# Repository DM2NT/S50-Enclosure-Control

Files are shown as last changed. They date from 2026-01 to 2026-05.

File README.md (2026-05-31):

# Seestar S50 Observatory Controller

**ESP32-basierte Wetterstation und automatische Schutzabdeckung für das Seestar S50 Teleskop**

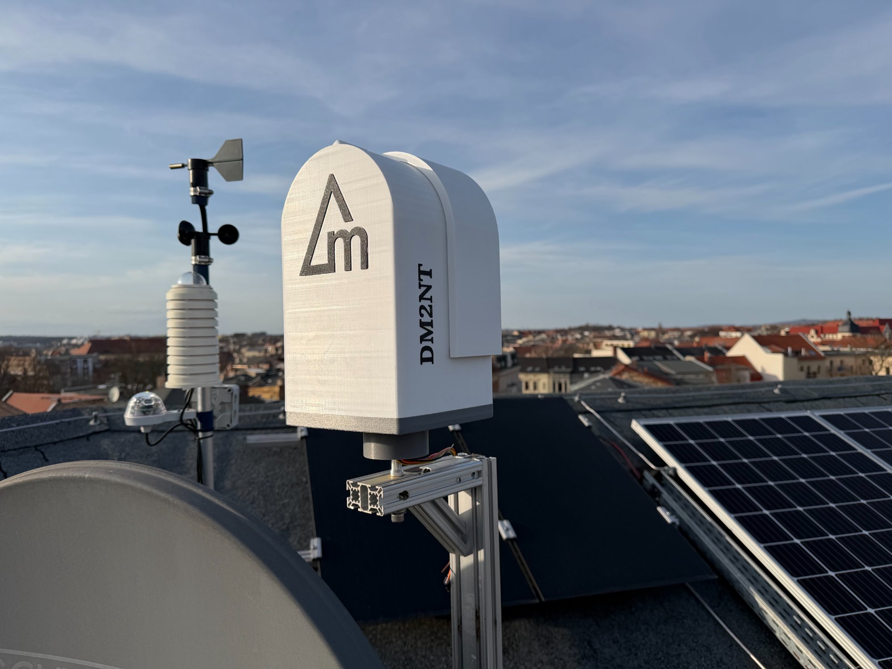
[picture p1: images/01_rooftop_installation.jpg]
Rooftop Installation


## Übersicht

Dieses Projekt bietet eine vollautomatische Wetterüberwachung und Teleskopschutz-Lösung für das Seestar S50. Bei ungünstigen Wetterbedingungen (Regen, Wind, hohe Luftfeuchtigkeit) schließt sich die motorisierte Abdeckung automatisch, um das Teleskop zu schützen.

**Hauptfunktionen:**
- ✅ Automatische Regenüberwachung (Hydreon RG-11)
- ✅ Temperatur- und Luftfeuchtigkeits-Überwachung (BME280)
- ✅ Taupunktberechnung mit Heizungssteuerung
- ✅ Motorisierte Schutzabdeckung (MG996R Servo)
- ✅ Seestar S50 Integration (automatisches Parken bei Schlechtwetter)
- ✅ Web-Interface für Steuerung und Monitoring
- ✅ GPS-Zeitabgleich (optional)

## Hardware

### Hauptkomponenten

| Komponente | Modell | Funktion |
|---|---|---|
| Mikrocontroller | ESP32 DevKit | Hauptsteuerung |
| Regensensor | Hydreon RG-11 | Niederschlagserkennung |
| Umweltsensor | BME280 | Temperatur, Luftfeuchtigkeit, Luftdruck |
| Servo | MS24 20kg | Abdeckungsmechanik |
| GPS-Modul | NEO-6M/7M | Zeitabgleich (optional) |
| Heizung | 3 Ohm 15W | Taupunkt-Schutz |

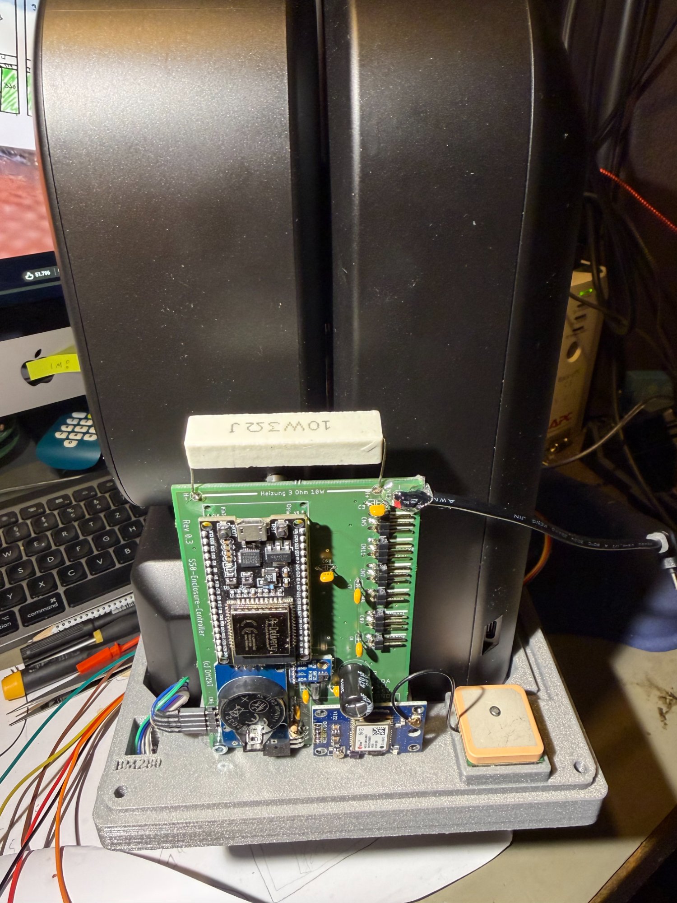
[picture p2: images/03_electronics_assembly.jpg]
Electronics Assembly


### Gehäuse

Das Gehäuse wurde mit einem **Bambu Lab 3D-Drucker** gefertigt:
- Material: PLA/PETG
- Wetterfest konzipiert
- Kabelführungen integriert
- Montage-Interfaces für Sensoren

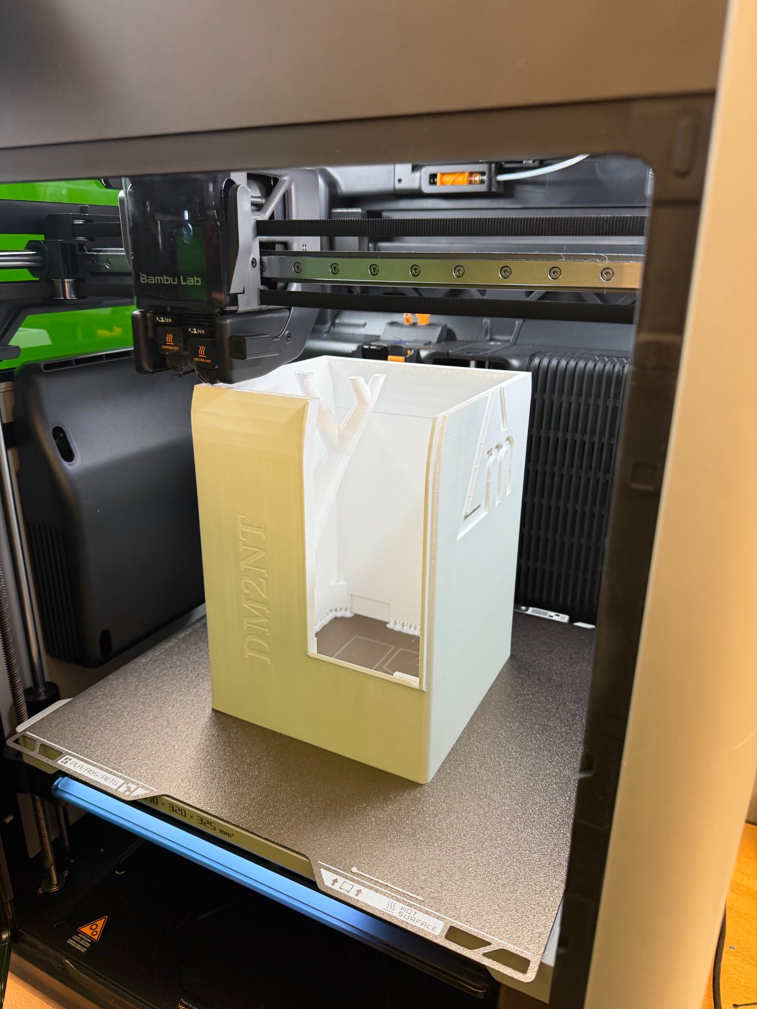
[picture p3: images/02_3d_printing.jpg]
3D Printing


## Pin-Belegung

### ESP32 Pins

```cpp
// Servo
#define SERVO_PIN 13

// Reed-Schalter (Position)
#define REED_CLOSED_PIN 32
#define REED_OPEN_PIN 33

// Wind-Sensor (Davis 6410)
#define WIND_PIN 27

// Heizung
#define HEATER_PIN 12

// RG-11 Regensensor
#define RAIN_RX_PIN 35
#define RAIN_TX_PIN 4

// GPS (optional)
#define GPS_RX_PIN 16
#define GPS_TX_PIN 17

// I2C (BME280)
SDA: GPIO 21
SCL: GPIO 22
```

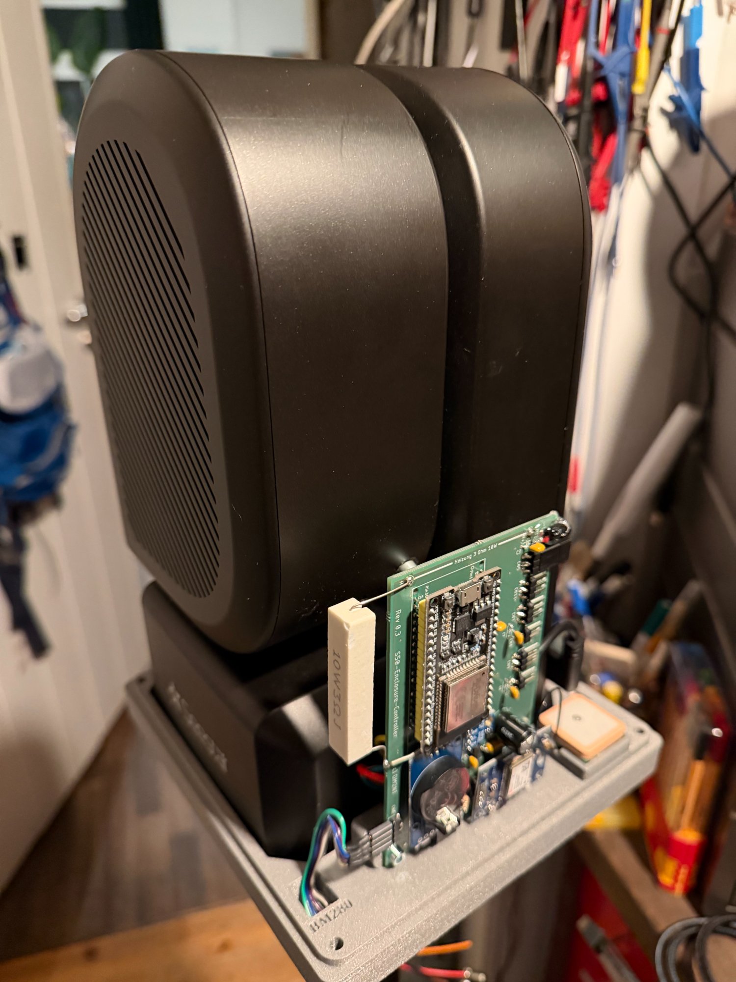
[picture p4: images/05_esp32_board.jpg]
ESP32 Board


## Installation

### 1. Arduino IDE Setup

```bash
# ESP32 Board Manager URL hinzufügen:
https://raw.githubusercontent.com/espressif/arduino-esp32/gh-pages/package_esp32_index.json

# Benötigte Bibliotheken installieren:
- ESP32Servo
- Adafruit BME280
- TinyGPSPlus
- AsyncTCP
- ESPAsyncWebServer
- Preferences
```

### 2. Firmware flashen

1. `.ino` Datei in Arduino IDE öffnen
2. Board auswählen: **ESP32 Dev Module**
3. Partition Scheme: **Minimal SPIFFS (1.9MB APP with OTA)**
4. Upload Speed: **921600**
5. Kompilieren und hochladen

### 3. Erste Konfiguration

Nach dem ersten Start öffnet der ESP32 einen **WiFi Access Point**:

```
SSID: S50-Enclosure-XXXXXX
Passwort: 12345678
IP: 192.168.4.1
```

Verbinden und WiFi-Zugangsdaten eingeben.

## Konfiguration

### RG-11 Regensensor DIP-Switches
!!! im Moment nicht funktionsfähig !!!

**Für ASCII "It's Raining" Mode:**

| DIP | Position | Funktion |
|-----|---|---|
| 1 | **ON** | Empfindlichkeit hoch |
| 2 | **ON** | Empfindlichkeit hoch |
| 3 | OFF | Keine 15-Min-Haltezeit |
| 5 | OFF | RS232 aktiv |
| 7 | **ON** | It's Raining Mode |
| 8 | OFF | Normal (kein Sleep) |

**Wichtig:** DIP 5 MUSS OFF sein für RS232!

### Heizungssteuerung

- Aktiviert wenn: `Temperatur < (Taupunkt + Hysterese)`
- Standard-Hysterese: **2.0°C**
- Heizleistung: **15W** (3 Ohm)

## Web-Interface

Das Web-Interface ist erreichbar unter der ESP32-IP:

**Hauptseite:**
- Live-Sensordaten (2s Refresh)
- Status: Regen, Wind, Temperatur, Luftfeuchtigkeit
- Steuerung: Öffnen, Schließen, Stopp
- Seestar S50 Status

**Einstellungen:**
- WiFi-Konfiguration
- Wind-Schwellwert  ( nicht integriert )
- Heizungs-Hysterese
- Seestar IP-Adresse
- GPS An/Aus

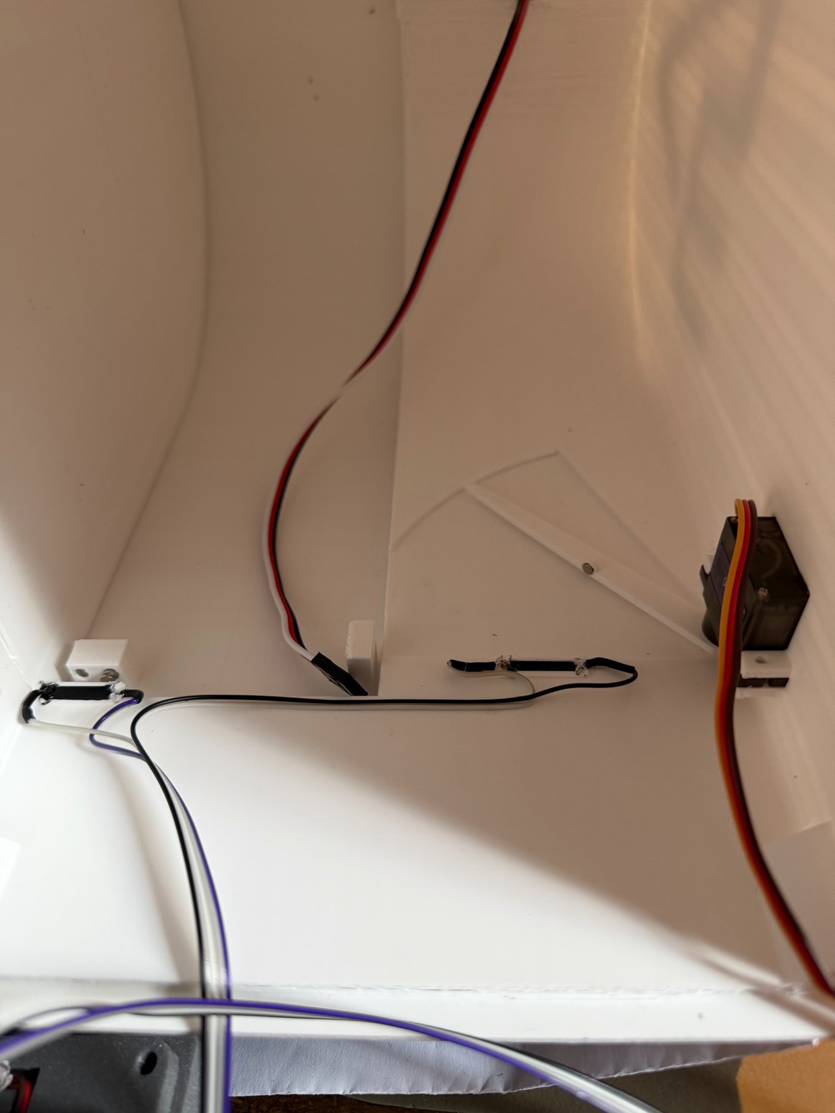
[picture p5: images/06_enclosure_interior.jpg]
Enclosure Interior


## Servo-Mechanik

Der Servo MS24 mit 20kg Drehmoment steuert die Abdeckung:

- Öffnen: 0° (Reed-Schalter 2)
- Geschlossen: 90° (Reed-Schalter 1)
- Sanftes Anfahren mit Beschleunigung
- Reed-Schalter als Endlagen-Sicherung

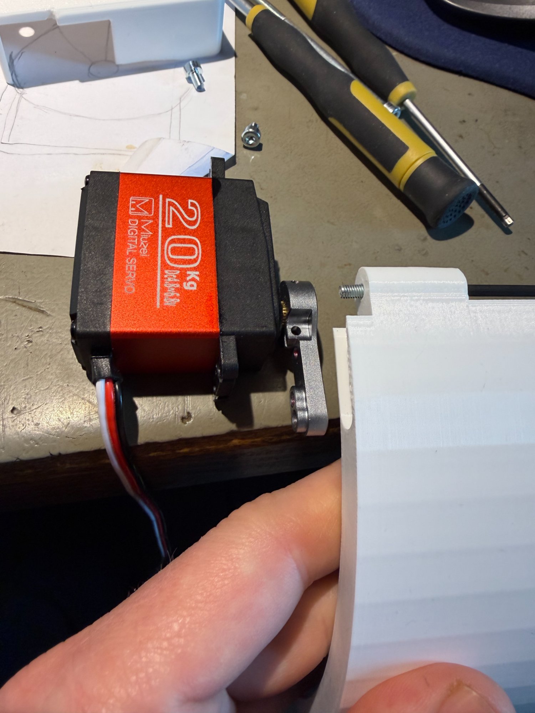
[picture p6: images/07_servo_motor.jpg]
Servo Motor

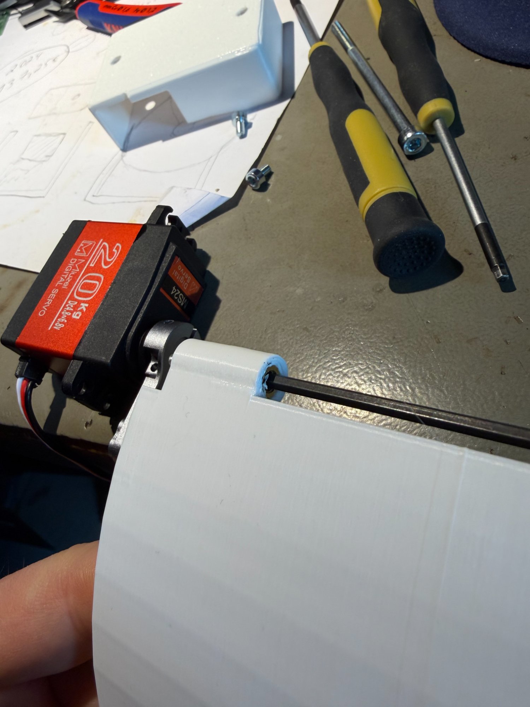
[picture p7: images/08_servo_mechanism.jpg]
Servo Mechanism


### 3D-gedruckte Teile

- Servo-Halterung
- Hebelarm (weiß, verstärkt)
- Gehäuse-Adapter

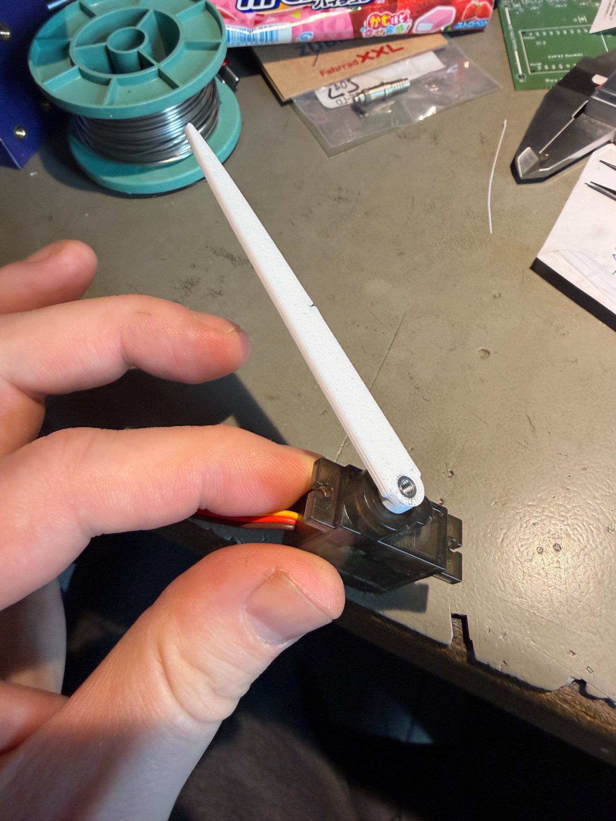
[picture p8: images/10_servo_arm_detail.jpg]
Servo Arm Detail


## Seestar S50 Integration

Bei Regen/Wind schaltet der Controller das Seestar automatisch ab und schließt die Klappe.

- im Moment nicht funktionsfähig

Das Teleskop wird geparkt, bevor die Abdeckung schließt.

## Sicherheitsfunktionen

1. **Regen-Notschließung:** Bei Regenerkennung → sofortige Schließung
2. **Wind-Notschließung:** Bei Überschreitung Schwellwert → Schließung
3. **Reed-Schalter:** Mechanische Endlagen-Sicherung
4. **Motor-Timeout:** Stoppt nach 10s bei fehlendem Reed-Signal
5. **Heizung:** Verhindert Beschlagen/Betauung

## OTA-Updates

Firmware-Updates über WiFi möglich:

```
http://ESP32_IP/update
```

**Wichtig:** Nur `.ino.bin` verwenden, NICHT `merged.bin`!

## Serial Monitor Debug

USB Serial (115200 Baud):
```
RG-11 UART initialisiert (RX=35, 9600 Baud, ASCII Mode)
  Warte auf RG-11 ASCII Daten (max 10s)...
  'Acc' Frame gefunden: Acc 0.00
✓ RG-11 Regensensor erkannt!

💧 RG-11: REGEN! Acc=1.00
⚠️ REGEN ERKANNT! (Acc=1.00) Starte Notschließung...
```

## Stromversorgung

- 5V 4A externes Netzteil 

**Wichtig:** Servo und ESP32 gemeinsame GND-Verbindung!

## Versionshistorie

- **v3.1** - ASCII-Protokoll RG-11, Boot-Erkennung angepasst
- **v3.0** - Umstellung auf ASCII "It's Raining" Mode
- **v2.2** - Slow Register #8 Bucket-Zähler
- **v0.4** - Heizung auf Innentemperatur, stabile Version

## Lizenz

MIT License - siehe LICENSE Datei

## Autor

**DM2NT** - Amateur Radio / Astrophotography  
YouTube: [DeltaMike2 Astronomie](https://youtube.com/@DeltaMike2)

## Danksagungen

Allen Irren, die sich das hier antun.

---

**73!** 📡🔭

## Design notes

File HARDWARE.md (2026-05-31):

# Hardware-Dokumentation

## Vollständige Komponentenliste

### Elektronik

| Komponente | Modell/Spezifikation | Menge | Beschaffung |
|---|---|---|---|
| ESP32 | DevKit V1 (30 Pin) | 1 | AliExpress/Amazon |
| Regensensor | Hydreon RG-11 | 1 | Hydreon/Conrad |
| Umweltsensor | BME280 (I2C) | 1 | Adafruit/AliExpress |
| Servo | MG996R 20kg | 1 | Amazon/AliExpress |
| GPS-Modul | NEO-6M oder NEO-7M | 1 | AliExpress (optional) |
| Reed-Schalter | NO (Normally Open) | 2 | Conrad/Reichelt |
| Heizwiderstand | 3 Ohm 15W | 1 | Reichelt |
| MOSFET | IRLZ44N | 1 | Reichelt |
| Widerstände | 10kΩ | 3 | Reichelt |
| Diode | 1N4007 | 1 | Reichelt |

### Mechanik & Gehäuse

| Komponente | Material | Hinweise |
|---|---|---|
| Gehäuse | PLA/PETG | 3D-Druck, wetterfest |
| Servo-Halterung | PETG | 3D-Druck, verstärkt |
| Hebelarm | PLA | 3D-Druck, weiß |
| M3 Schrauben | Edelstahl | Diverse Längen |
| M4 Schrauben | Edelstahl | Servo-Befestigung |

### Kabel

| Typ | Spezifikation | Länge | Verwendung |
|-----|---|---|---|
| Stromkabel | 1.5mm² | Variabel | 230V → Netzteile |
| Signalkabel | 0.5mm² geschirmt | 5m | RG-11, Anemometer |
| Dupont-Kabel | Female-Female | 20cm | ESP32-Verbindungen |
| USB-Kabel | Micro-USB | 2m | ESP32 Stromversorgung |

### Netzteile

| Ausgang | Leistung | Verwendung |
|---|---|---|
| 5V DC | 4A | Platine |

## Detaillierte Verkabelung

### ESP32 Pinout

```
                    ESP32 DevKit V1
                  ┌─────────────────┐
              3V3 │1              30│ GND
              GND │2              29│ GPIO 23
      (Touch) D15 │3              28│ GPIO 22 ──┐ SCL (BME280)
      (Touch)  D2 │4              27│ TXD      │
      (Touch)  D4 │5              26│ RXD      │
              D16 │6 GPS_RX       25│ GPIO 21 ─┼─ SDA (BME280)
              D17 │7 GPS_TX       24│ GND      │
               D5 │8              23│ GPIO 19  │
              D18 │9              22│ GPIO 18  │
              D19 │10             21│ GPIO 5   │
              GND │11             20│ GPIO 17  │
              D21 │12             19│ GPIO 16  │
       RX0    D3  │13             18│ GPIO 4  ─── RAIN_TX
       TX0    D1  │14             17│ GPIO 2   │
      (Touch) D22 │15             16│ GPIO 15  │
              D23 │16             15│ GND      │
              GND │17             14│ GPIO 13 ─── SERVO_PIN
              3V3 │18             13│ GPIO 12 ─── HEATER_PIN
               EN │19             12│ GPIO 14  │
     ADC2_0   VP  │20             11│ GPIO 27 ─── WIND_PIN
     ADC2_3   VN  │21             10│ GPIO 26  │
   ADC2_4/34  D34 │22              9│ GPIO 25  │
   ADC2_5/35  D35 │23 RAIN_RX      8│ GPIO 33 ─── REED_OPEN
   ADC2_6/32  D32 │24 REED_CLOSED  7│ GPIO 32  │
   ADC2_7/33  D33 │25              6│ TDI/D5   │
   ADC1_4/25  D25 │26              5│ 3V3      │
   ADC1_5/26  D26 │27              4│ TDO/D18  │
   ADC1_6/27  D27 │28              3│ D23      │
   ADC1_7/14  D14 │29              2│ D22      │
   ADC1_0/12  D12 │30              1│ TXD      │
                  └─────────────────┘
```

### RG-11 Regensensor

**Anschluss:**
```
RG-11          ESP32
────────────────────────────
1 (+12V)   →   Externes 12V Netzteil
2 (GND)    →   GND (gemeinsam)
3 (OUT)    →   Pin 35 (RAIN_RX)
               + 10kΩ Pull-Down zu GND
```

**Wichtig:**
- RG-11 sendet 5V → direkter Anschluss an ESP32 ist OK (INPUT_ONLY Pin 35)
- Pull-Down Widerstand verhindert "floating" Pin
- UART Konfiguration: 9600 Baud, 8N1, ASCII Mode

**DIP-Switch Einstellung:**
```
┌─────────────────────────────┐
│  1  2  3  4  5  6  7  8     │
│ ON ON OFF OFF OFF OFF ON OFF│
└─────────────────────────────┘
```

### Davis Anemometer 6410

**Anschluss:**
```
Davis 6410     ESP32
────────────────────────────
Schwarz    →   Pin 27 (WIND_PIN)
Rot        →   3.3V
Grün       →   GND
Gelb       →   Nicht verbunden
```

**Schaltung:**
```
3.3V ──┬── 10kΩ ──┬── Pin 27
       │          │
       └── Reed ──┘ (im Anemometer)
                  │
                 GND
```

**Funktionsweise:**
- Jede Umdrehung → 1 Impuls (Reed-Schalter)
- Wind-Geschwindigkeit = `(1492 / T) * 1.60934` km/h
- T = Zeit zwischen Impulsen in ms

### BME280 Umweltsensor

**Anschluss (I2C):**
```
BME280         ESP32
────────────────────────────
VCC        →   3.3V
GND        →   GND
SCL        →   Pin 22 (SCL)
SDA        →   Pin 21 (SDA)
```

**I2C-Adresse:** `0x76` (Standard) oder `0x77`

### Servo MG996R

**Anschluss:**
```
Servo          Versorgung
────────────────────────────
Braun (GND) →  GND (gemeinsam mit ESP32!)
Rot (VCC)   →  5V/2A Netzteil
Orange (PWM)→  Pin 13 (ESP32)
```

- GND zwischen ESP32 und Servo-Netzteil verbinden

**Position:**
- 0° = Offen
- 90° = Geschlossen
- Sanfte Bewegung (1° pro 20ms)

### Reed-Schalter (Endlagen)

**Geschlossen-Position:**
```
Reed 1         ESP32
────────────────────────────
Pin 1      →   Pin 32 (REED_CLOSED)
Pin 2      →   GND
```

**Offen-Position:**
```
Reed 2         ESP32
────────────────────────────
Pin 1      →   Pin 33 (REED_OPEN)
Pin 2      →   GND
```

**Funktionsweise:**
- `INPUT_PULLUP` Mode
- Geschlossen: LOW = Magnet in Nähe
- Offen: HIGH = kein Magnet

### Heizung (Taupunkt-Schutz)

**Schaltung:**
```
12V ──┬── Heizwiderstand 3Ω/15W ──┬── GND
      │                           │
      └── MOSFET (IRLZ44N) ───────┘
              │
              ├── Gate: Pin 12 (ESP32)
              ├── 10kΩ Pull-Down (Gate-GND)
              └── 1N4007 Diode (parallel zum Widerstand)
```

**PWM-Steuerung:**
- Frequenz: 1000 Hz
- Duty Cycle: 0-255 (aktuell: 255 = 100%)

### GPS-Modul (Optional)

**Anschluss:**
```
GPS NEO-6M     ESP32
────────────────────────────
VCC        →   3.3V (NICHT 5V!)
GND        →   GND
TX         →   Pin 16 (GPS_RX)
RX         →   Pin 17 (GPS_TX)
```

**UART:** 9600 Baud, 8N1

## Montage-Hinweise

### Gehäuse

1. **3D-Druck Einstellungen:**
   - Layer: 0.2mm
   - Infill: 20%
   - Wandstärke: 3-4 Perimeter
   - Support: Ja (für Überhänge)

2. **Wetterfest machen:**
   - Alle Kabel-Durchführungen mit Silikon abdichten
   - Reed-Schalter in wasserdichten Gehäusen
   - RG-11 nach oben montieren (Kabel nach unten)

3. **Kabelführung:**
   - Zugentlastung vorsehen
   - Kabelbinder verwenden
   - Beschriftung empfohlen

### Servo-Mechanik

1. **Hebelarm:**
   - 3D-gedruckt aus PLA/PETG
   - Verstärkung mit 100% Infill
   - M3 Schraube zur Befestigung

2. **Servo-Halterung:**
   - Mit M4 Schrauben am Gehäuse befestigen
   - Spielfrei montieren
   - Bewegungsfreiheit prüfen

### Sensor-Platzierung

**RG-11 Regensensor:**
- Horizontal montieren
- Freie Sicht nach oben (keine Überhänge)
- Mindestens 30cm von Wänden entfernt

**BME280:**
- Im Gehäuse, aber belüftet
- Vor direkter Sonneneinstrahlung schützen
- Nicht direkt über Heizung

## Stromverbrauch

| Komponente | Standby | Aktiv | Max |
|---|---|---|-----|
| ESP32 | 80mA | 150mA | 250mA |
| Servo | 10mA | 500mA | 2A |
| BME280 | 3µA | 3mA | 5mA |
| GPS | 20mA | 50mA | 50mA |
| Heizung | 0mA | 1.25A | 1.25A |
| **Gesamt** | ~100mA | ~700mA | ~3.5A |

## Fehlersuche Hardware

### RG-11 keine Daten

1. DIP-Switches prüfen (Foto im Web suchen)
2. 12V Versorgung messen
3. Pull-Down Widerstand 10kΩ vorhanden?
4. Serial Monitor: Zeichen empfangen?

### Servo ruckt/zittert

1. SStromversorgung 5V/2A prüfen
2. GND-Verbindung ESP32 ↔ Servo OK?
3. Kabel zu lang? (max 50cm empfohlen)
4. Mechanische Blockade?

### Heizung funktioniert nicht

1. MOSFET richtig gepolt?
2. Pull-Down 10kΩ Gate-GND vorhanden?
3. Freilauf-Diode 1N4007 vorhanden?
4. 5V Versorgung messen

### BME280 nicht erkannt

1. I2C-Adresse prüfen: `0x76` oder `0x77`
2. SDA/SCL vertauscht?
3. Pull-Up Widerstände vorhanden? (meist auf Modul)
4. 3.3V (NICHT 5V!)

### Reed-Schalter falsch

1. `INPUT_PULLUP` Mode gesetzt?
2. Magnet-Abstand zu groß? (max 2cm)
3. Polarität egal bei Reed-Schaltern
4. Kabel-Bruch?

## Wartung

**Regelmäßig (1x Monat):**
- RG-11 Sensor reinigen (Isopropanol)
- Anemometer auf Leichtgängigkeit prüfen
- Servo-Bewegung testen
- Schrauben nachziehen

**Halbjährlich:**
- Gehäuse-Dichtungen prüfen
- Kabel auf Brüche untersuchen
- BME280 kalibrieren (Referenz-Thermometer)

**Jährlich:**
- Firmware-Update
- Komplette Funktionsprüfung
- Backup der Einstellungen

---

**Bei Fragen: Issues auf GitHub öffnen!**

73!

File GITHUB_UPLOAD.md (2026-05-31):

# GitHub Upload - Schritt für Schritt

## Variante 1: GitHub Desktop (Einfach!)

### 1. GitHub Desktop installieren
- Download: https://desktop.github.com/
- Installieren und mit GitHub-Account anmelden

### 2. Neues Repository erstellen
1. **File → New Repository**
2. Name: `seestar-observatory`
3. Description: `ESP32-based weather station and automatic cover for Seestar S50 telescope`
4. Local Path: Ordner auswählen wo Projekt liegt
5. Git Ignore: None (wir haben schon .gitignore)
6. License: MIT (oder None, wir haben schon LICENSE)
7. **Create Repository**

### 3. Dateien committen
1. Alle Dateien sollten in der Liste erscheinen
2. Commit Message: `Initial commit - Firmware v3.1`
3. **Commit to main**

### 4. Zu GitHub hochladen
1. **Publish repository**
2. Haken bei "Keep this code private" entfernen (für öffentlich)
3. **Publish Repository**

**Fertig!** 🎉

Repository URL: `https://github.com/DEIN_USERNAME/seestar-observatory`

---

## Variante 2: Git Kommandozeile (Fortgeschritten)

### 1. GitHub Repository erstellen
1. Zu https://github.com/new gehen
2. Repository Name: `seestar-observatory`
3. Description: `ESP32-based weather station and automatic cover for Seestar S50 telescope`
4. Public
5. **NICHT** "Initialize with README" anklicken (haben wir schon!)
6. **Create Repository**

### 2. Git initialisieren
```bash
cd /pfad/zum/seestar-observatory

# Git initialisieren
git init

# Remote hinzufügen (DEIN_USERNAME anpassen!)
git remote add origin https://github.com/DEIN_USERNAME/seestar-observatory.git

# Dateien hinzufügen
git add .

# Ersten Commit
git commit -m "Initial commit - Firmware v3.1"

# Zu GitHub hochladen
git branch -M main
git push -u origin main
```

**Benutzername & Passwort:**
- Username: Dein GitHub Username
- Password: **Personal Access Token** (nicht Passwort!)
  - Erstellen unter: https://github.com/settings/tokens
  - Scope: `repo` auswählen

---

## Nach dem Upload

### README anpassen
1. Auf GitHub Repository gehen
2. README.md öffnen
3. Bei Bedarf YouTube-Link, Callsign, etc. anpassen
4. **Commit changes**

### Releases erstellen
```bash
# Tag für v3.1 erstellen
git tag -a v3.1 -m "Version 3.1 - ASCII Protocol RG-11"
git push origin v3.1
```

Auf GitHub:
1. **Releases** → **Create a new release**
2. Tag: `v3.1`
3. Title: `v3.1 - ASCII Protocol RG-11`
4. Description: Changelog einfügen
5. `.ino.bin` Datei anhängen (für OTA-Updates!)
6. **Publish release**

### Repository-Einstellungen

**About (rechts oben):**
- Description: Kurzbeschreibung
- Website: YouTube-Kanal oder Homepage
- Topics: `esp32`, `arduino`, `weather-station`, `astronomy`, `seestar-s50`

**README Badges hinzufügen (optional):**
```markdown
![License: MIT](https://img.shields.io/badge/License-MIT-yellow.svg)
![Arduino](https://img.shields.io/badge/Arduino-IDE-00979D?logo=arduino)
![ESP32](https://img.shields.io/badge/ESP32-DevKit-blue)
```

---

## Updates hochladen

### Neue Version kompilieren
1. Code ändern
2. Version-Nummer erhöhen: `#define FIRMWARE_VERSION "3.2"`
3. Arduino IDE: Kompilieren

### Zu Git committen
```bash
git add .
git commit -m "v3.2 - Bug fixes"
git push
```

### Release erstellen
```bash
git tag -a v3.2 -m "Version 3.2 - Bug fixes"
git push origin v3.2
```

---

## Tipps

**Gute Commit-Messages:**
- ✅ `Fix RG-11 boot detection`
- ✅ `Add wind sensor calibration`
- ❌ `update`
- ❌ `fix stuff`

**Issues aktivieren:**
- Settings → Features → Issues ✓
- Für Bug-Reports und Feature-Requests

**Wiki aktivieren:**
- Settings → Features → Wiki ✓
- Für erweiterte Dokumentation

**GitHub Actions (CI/CD):**
- Automatisches Kompilieren bei jedem Push
- `.github/workflows/arduino.yml` erstellen
- Template: https://github.com/arduino/compile-sketches

---

**Bei Fragen: DM2NT kontaktieren!**

73! 📡

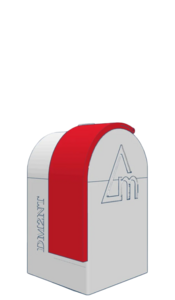
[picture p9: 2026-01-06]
assets/status_images/S50_Geschlossen_rot.png

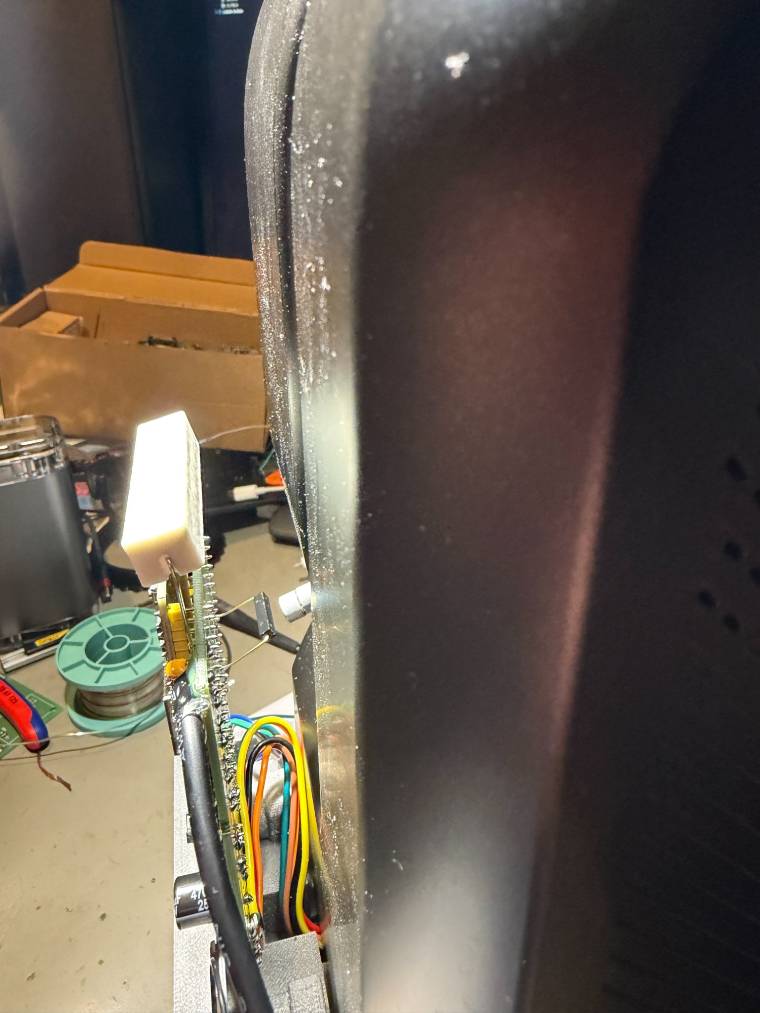
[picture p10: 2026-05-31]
images/04_cable_routing.jpg

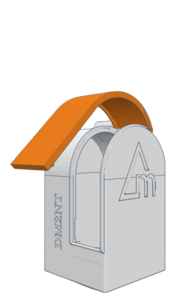
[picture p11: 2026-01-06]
assets/status_images/S50_halboffen_orange.png

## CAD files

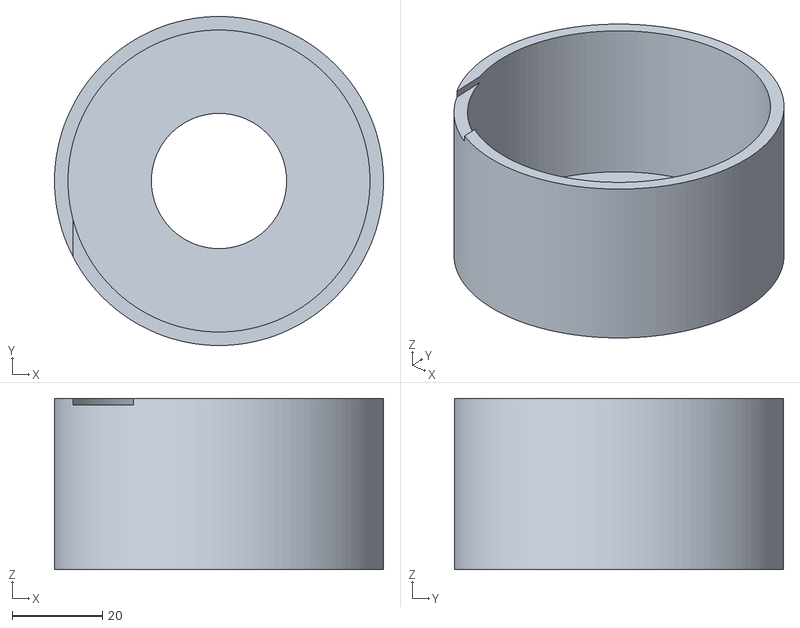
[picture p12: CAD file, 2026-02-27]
3d-models/S50 Schleifringschutz_Rev0.8.stl
73.0 x 73.0 x 38.0

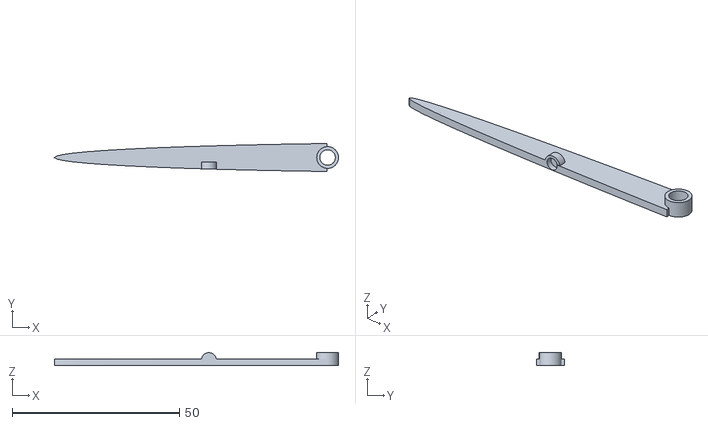
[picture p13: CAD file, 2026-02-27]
3d-models/S50 Verriegelung Rev 0.8.stl
84.8 x 8.35 x 4.00

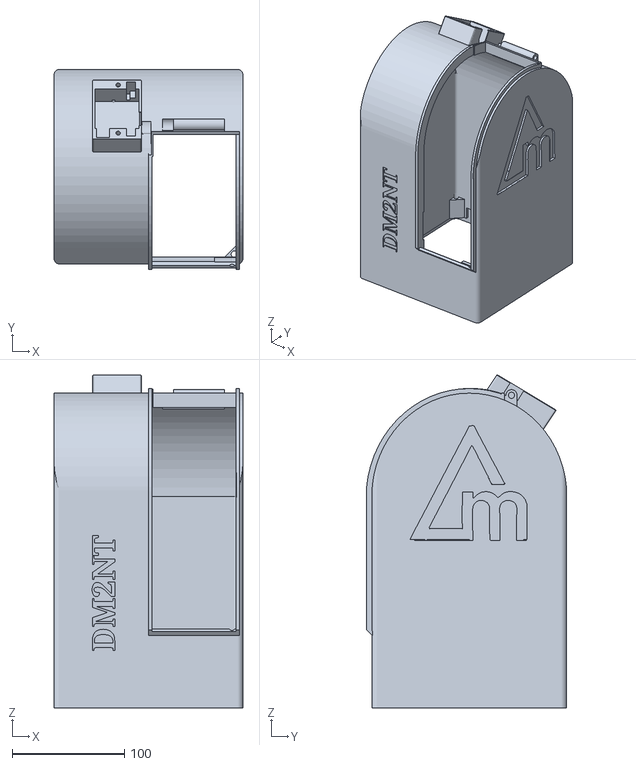
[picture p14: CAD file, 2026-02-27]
3d-models/S50 Housing Rev0.8.stl
168.0 x 178.0 x 296.0

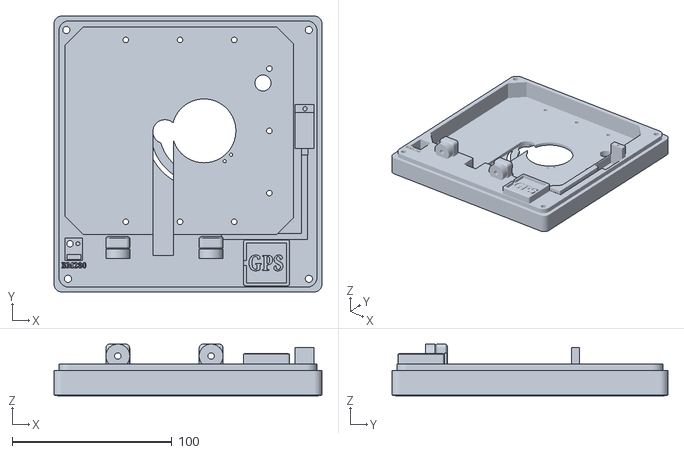
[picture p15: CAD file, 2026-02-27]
3d-models/S50 Boden Rev 0.8.stl
168.0 x 173.0 x 32.5

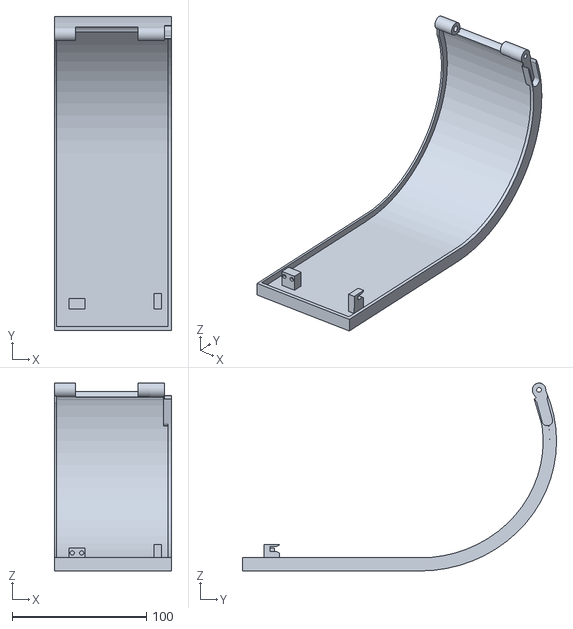
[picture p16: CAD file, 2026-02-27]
3d-models/S50 Klappe Rev 0.8.stl
87.5 x 234.0 x 140.1

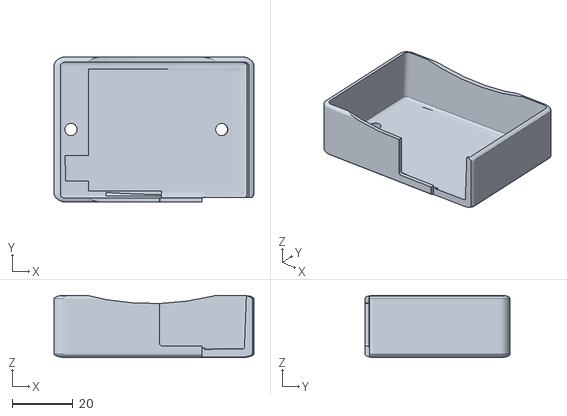
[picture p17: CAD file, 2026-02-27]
3d-models/S50 Servo Abdeckung Rev0.8.stl
66.0 x 48.0 x 20.5

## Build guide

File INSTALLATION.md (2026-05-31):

# Installation & Setup

## Voraussetzungen

### Software
- Arduino IDE 2.x (empfohlen) oder 1.8.x
- ESP32 Board Support
- USB-Treiber (CP210x oder CH340)

### Hardware
- ESP32 DevKit V1
- USB-Kabel (Micro-USB)
- Computer mit USB-Port

## 1. Arduino IDE einrichten

### 1.1 ESP32 Board Manager installieren

1. Arduino IDE öffnen
2. **Datei → Einstellungen**
3. "Zusätzliche Boardverwalter-URLs" hinzufügen:
   ```
   https://raw.githubusercontent.com/espressif/arduino-esp32/gh-pages/package_esp32_index.json
   ```
4. **OK** klicken
5. **Werkzeuge → Board → Boardverwalter**
6. Nach "esp32" suchen
7. "esp32 by Espressif Systems" installieren (Version 2.0.x empfohlen)

### 1.2 Bibliotheken installieren

**Sketch → Bibliothek einbinden → Bibliotheken verwalten**

Folgende Bibliotheken installieren:

| Bibliothek | Version | Autor |
|---|---|---|
| ESP32Servo | Latest | Kevin Harrington |
| Adafruit BME280 Library | Latest | Adafruit |
| Adafruit Unified Sensor | Latest | Adafruit |
| TinyGPSPlus | Latest | Mikal Hart |
| AsyncTCP | Latest | me-no-dev |
| ESPAsyncWebServer | Latest | me-no-dev |

**AsyncTCP und ESPAsyncWebServer manuell installieren:**

1. AsyncTCP: https://github.com/me-no-dev/AsyncTCP
   - "Code → Download ZIP"
   - **Sketch → Bibliothek einbinden → .ZIP-Bibliothek hinzufügen**

2. ESPAsyncWebServer: https://github.com/me-no-dev/ESPAsyncWebServer
   - "Code → Download ZIP"
   - **Sketch → Bibliothek einbinden → .ZIP-Bibliothek hinzufügen**

## 2. Firmware kompilieren

### 2.1 Board-Einstellungen

**Werkzeuge** Menü:

| Einstellung | Wert |
|---|---|
| Board | "ESP32 Dev Module" |
| Upload Speed | 921600 |
| CPU Frequency | 240MHz (WiFi/BT) |
| Flash Frequency | 80MHz |
| Flash Mode | QIO |
| Flash Size | 4MB |
| Partition Scheme | **Minimal SPIFFS (1.9MB APP with OTA/190KB SPIFFS)** |
| Core Debug Level | None (oder "Debug" für Fehlersuche) |
| PSRAM | Disabled |
| Port | Automatisch erkennen (z.B. COM3, /dev/ttyUSB0) |

### 2.2 Kompilieren & Hochladen

1. `.ino` Datei öffnen
2. **Werkzeuge → Port** → ESP32-Port auswählen
3. **Sketch → Hochladen** (Pfeil-Symbol oder Strg+U)

**Wichtig während Upload:**
- ESP32 am USB angeschlossen lassen
- Bei manchen Boards: BOOT-Taste gedrückt halten beim Start

**Erfolgreiche Ausgabe:**
```
Leaving...
Hard resetting via RTS pin...
```

## 3. Erstkonfiguration

### 3.1 WiFi Access Point

Nach dem ersten Start öffnet der ESP32 einen Access Point:

```
SSID: S50-Enclosure-XXXXXX
Passwort: 12345678
IP-Adresse: 192.168.4.1
```

**XXXXXX** = Letzte 6 Zeichen der MAC-Adresse

### 3.2 WiFi-Zugangsdaten eingeben

1. Mit Smartphone/Laptop verbinden
2. Browser öffnen: `http://192.168.4.1`
3. Auf "WiFi Einstellungen" klicken
4. SSID und Passwort eingeben
5. **Speichern & Neustart**

ESP32 startet neu und verbindet sich mit dem WiFi.

### 3.3 IP-Adresse herausfinden

**Methode 1: Serial Monitor**
```
Arduino IDE → Werkzeuge → Serieller Monitor
Baudrate: 115200

Ausgabe:
...
WiFi verbunden!
IP-Adresse: 192.168.1.123
```

**Methode 2: Router-Admin-Panel**
- Router-Webinterface öffnen
- DHCP-Client-Liste suchen
- "S50-Enclosure" oder "ESP32" finden

**Methode 3: Netzwerk-Scanner**
- Fing (Android/iOS App)
- Advanced IP Scanner (Windows)
- Angry IP Scanner (Linux/Mac)

## 4. Hardware verbinden

**ACHTUNG: ESP32 NICHT am USB, während Hardware verbunden wird!**

### 4.1 Reihenfolge

1. ✅ Alle Netzteile **AUS**
2. ✅ ESP32 **NICHT** am USB
3. ✅ Sensoren verbinden (siehe HARDWARE.md)
4. ✅ Servo verbinden (6V Netzteil **AUS**)
5. ✅ Heizung verbinden (12V Netzteil **AUS**)
6. ✅ **GND-Verbindungen** prüfen!
7. ✅ Polaritäten prüfen
8. ✅ Kurzschlüsse ausschließen
9. ✅ Netzteile einschalten
10. ✅ ESP32 am USB verbinden

### 4.2 Erste Funktionstests

**Serial Monitor (115200 Baud):**

```
========================================
  Seestar S50 Sternwarten-Controller
  Firmware v3.1
  DM2NT 2025
========================================

WiFi verbunden!
IP-Adresse: 192.168.1.123

BME280 Init...
✓ BME280 gefunden!
  Temperatur: 21.3°C
  Luftfeuchte: 45%

RG-11 UART initialisiert (RX=35, 9600 Baud, ASCII Mode)
  Warte auf RG-11 ASCII Daten (max 10s)...
  'Acc' Frame gefunden: Acc 0.00
✓ RG-11 Regensensor erkannt!

GPS Module Init (optional)...
✓ GPS-Modul gefunden!

Web Server gestartet!
OTA Update bereit auf http://192.168.1.123/update
```

**Web-Interface testen:**
1. Browser: `http://ESP32_IP`
2. Alle Sensorwerte prüfen
3. "Öffnen" Button → Servo bewegt sich?
4. Reed-Schalter-Status prüfen

## 5. Feineinstellungen

### 5.1 Wind-Schwellwert

**Standard:** 40 km/h

**Anpassen:**
1. Web-Interface → "Wind Einstellungen"
2. Neuen Wert eingeben (z.B. 50 km/h)
3. **Speichern**

**Tipp:** Bei exponierter Lage höheren Wert wählen!

### 5.2 Heizungs-Hysterese

**Standard:** 2.0°C

**Bedeutung:**
```
Heizung AN wenn:  Innentemperatur < (Taupunkt + 2.0°C)
Heizung AUS wenn: Innentemperatur > (Taupunkt + 2.0°C)
```

**Anpassen:**
1. Web-Interface → "Heizungs-Einstellungen"
2. Wert eingeben (0.5 - 5.0°C)
3. **Speichern**

### 5.3 Seestar S50 IP-Adresse

**Wichtig:** Damit automatisches Parken funktioniert!

1. Seestar S50 einschalten
2. IP-Adresse herausfinden (Seestar App)
3. Web-Interface → "Seestar Einstellungen"
4. IP eingeben (z.B. `192.168.1.45`)
5. **Speichern**

**Test:**
```
http://SEESTAR_IP:8080/api/v1/system/state
```
→ Sollte JSON zurückgeben

### 5.4 GPS-Modul (Optional)

**Aktivieren:**
1. Web-Interface → "GPS Einstellungen"
2. Haken bei "GPS aktiviert"
3. **Speichern & Neustart**

**Deaktivieren:**
- Haken entfernen → spart 50mA Stromverbrauch

## 6. Servo kalibrieren

### 6.1 Reed-Schalter Position finden

**Geschlossen (90°):**
1. Abdeckung manuell GANZ schließen
2. Reed-Schalter so positionieren, dass Signal LOW
3. Web-Interface prüfen: "Reed Geschlossen: ✓"

**Offen (0°):**
1. Abdeckung manuell GANZ öffnen
2. Reed-Schalter so positionieren, dass Signal LOW
3. Web-Interface prüfen: "Reed Offen: ✓"

### 6.2 Bewegungstest

**Serial Monitor:**
```
Öffne Abdeckung...
Servo: 90° → 89° → 88° → ... → 1° → 0°
✓ Reed OFFEN erreicht!
Abdeckung geöffnet!
```

**Falls Probleme:**
- Servo-Richtung vertauscht? → Hardware umbauen
- Reed-Schalter zu weit? → Näher positionieren
- Motor stoppt zu früh? → Timeout erhöhen (Code)

## 7. RG-11 Regensensor

### 7.1 DIP-Switches einstellen

**ASCII "It's Raining" Mode:**

```
  RG-11 DIP-Switches (Rückseite)
┌─────────────────────────────────┐
│ ┌─┬─┬─┬─┬─┬─┬─┬─┐               │
│ │1│2│3│4│5│6│7│8│               │
│ ├─┼─┼─┼─┼─┼─┼─┼─┤               │
│ │▲│▲│ │ │ │ │▲│ │ ON            │
│ │ │ │▼│▼│▼│▼│ │▼│ OFF           │
│ └─┴─┴─┴─┴─┴─┴─┴─┘               │
└─────────────────────────────────┘
```

| DIP | Position | Funktion |
|-----|---|---|
| 1 | **ON** | Empfindlichkeit hoch |
| 2 | **ON** | Empfindlichkeit hoch |
| 3 | OFF | Keine Haltezeit |
| 5 | **OFF** | RS232 aktiv (WICHTIG!) |
| 7 | **ON** | It's Raining Mode |
| 8 | OFF | Normal |

### 7.2 Test

**Wasser auf RG-11 sprühen:**

Serial Monitor sollte zeigen:
```
💧 RG-11: REGEN! Acc=1.00
⚠️ REGEN ERKANNT! (Acc=1.00) Starte Notschließung...
```

Web-Interface:
- Status: **REGEN**
- Menge: **1.00 mm**
- Abdeckung: **GESCHLOSSEN**

## 8. OTA-Updates

**Firmware ohne USB-Kabel aktualisieren:**

1. Neue `.ino` Datei kompilieren
2. **Sketch → Kompilierte Binärdatei exportieren**
3. Datei finden: `Seestar_S50_Sternwarte_vXX.ino.bin`
4. Browser: `http://ESP32_IP/update`
5. Datei auswählen: **NUR die .ino.bin** (NICHT merged.bin!)
6. Upload → Warten → Neustart

**WICHTIG:**
- Während OTA-Update NICHT die Stromversorgung unterbrechen!
- NUR `.ino.bin` verwenden
- Nach Update: Einstellungen prüfen

## 9. Backup & Restore

### 9.1 Einstellungen sichern

ESP32 speichert alle Einstellungen in **NVS (Non-Volatile Storage)**:
- WiFi-Zugangsdaten
- Wind-Schwellwert
- Heizungs-Hysterese
- Seestar IP
- GPS An/Aus

**Backup erstellen:**
1. Serial Monitor öffnen (115200 Baud)
2. Einstellungen notieren:
   ```
   Wind-Schwellwert: 40 km/h
   Heizungs-Hysterese: 2.0°C
   Seestar IP: 192.168.1.45
   GPS: Aktiviert
   ```

**Alternativ:** Esptool.py NVS auslesen
```bash
esptool.py --port COM3 read_flash 0x9000 0x5000 nvs_backup.bin
```

### 9.2 Nach Firmware-Update

**Einstellungen bleiben erhalten!**

Falls zurücksetzen nötig:
1. Web-Interface → "System-Reset"
2. Oder: Reset-Button 10s gedrückt halten → AP-Modus

## 10. Troubleshooting

### Upload schlägt fehl

**"Failed to connect to ESP32"**
- USB-Kabel prüfen (manche sind nur Ladekabel!)
- Richtigen COM-Port gewählt?
- BOOT-Taste gedrückt halten beim Upload-Start
- USB-Treiber installiert? (CP210x/CH340)

**"Sketch zu groß"**
- Partition Scheme: "Minimal SPIFFS" gewählt?
- Alte Bibliotheken löschen
- Debug-Level auf "None"

### WiFi verbindet nicht

1. SSID und Passwort korrekt?
2. 2.4 GHz WiFi? (ESP32 kann KEIN 5 GHz!)
3. SSID sichtbar? (keine Hidden SSID)
4. Zu weit vom Router? (max 20m empfohlen)

### Serial Monitor zeigt Müll

- Baudrate: **115200** einstellen!
- "Both NL & CR" als Zeilenende
- USB-Kabel tauschen

### Sensoren werden nicht erkannt

**BME280:**
```
I2C Scanner laufen lassen:
File → Examples → Wire → i2c_scanner
```

**RG-11:**
- DIP 5 = OFF?
- Pull-Down 10kΩ vorhanden?
- 12V Versorgung?

**GPS:**
- 3.3V (NICHT 5V!)
- TX ↔ RX richtig?
- Draußen testen (Sicht zum Himmel)

## 11. Logs & Debug

### Serial Monitor aktivieren

```cpp
// In Arduino IDE:
Werkzeuge → Core Debug Level → "Debug"
```

**Ausgabe:**
```
[D][WiFiClient.cpp:125] connect(): Connected to 192.168.1.45:8080
[D][HTTPClient.cpp:334] POST: http://192.168.1.45:8080/api/v1/telescope/park
```

### Log-Dateien

ESP32 hat KEIN Dateisystem für Logs!

**Alternative:** Syslog-Server
```cpp
// Externe Bibliothek: Syslog
// Logs an Raspberry Pi / NAS senden
```

## Support

**Probleme?**
- GitHub Issues öffnen
- Serial Monitor Log anhängen
- Hardware-Fotos hochladen
- Firmware-Version angeben

**73!** 📡

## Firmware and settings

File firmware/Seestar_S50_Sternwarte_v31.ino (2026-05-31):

/*
 * Seestar S50 Gehäuse-Steuerung v3.0
 * ESP32 WROOM-32
 * 
 * Features:
 * - WiFi-Manager für einfache WLAN-Konfiguration
 * - Homepage mit Sensordaten, Status und Reed-LEDs
 * - Settings-Seite für Details
 * - Intelligente Öffnen/Schließen-Logik mit Reed-Checks
 * - RG-11 Regensensor (optional, auto-detect)
 * - RTC/GPS Sync mit flüssiger Sekundenanzeige
 * - Optimiertes Sensor-Timing (Wetter 15s, RTC 60s)
 */

#include <WiFi.h>
#include <WiFiManager.h>  // https://github.com/tzapu/WiFiManager
#include <DNSServer.h>
#include <ESP32Ping.h>
#include <ESPAsyncWebServer.h>
#include <Preferences.h>
#include <ESP32Servo.h>
#include <Wire.h>
#include <SparkFunHTU21D.h>
#include <Adafruit_BMP085.h>  // BMP180
#include <Adafruit_BMP280.h>  // BMP280
#include <RTClib.h>
#include <TinyGPSPlus.h>
#include <HardwareSerial.h>
#include <driver/uart.h>  // Für uart_set_line_inverse()
#include <Update.h>
#include <LittleFS.h>
#include <HTTPClient.h>

// ============= KONFIGURATION =============

#define FIRMWARE_VERSION "3.1"

// GitHub Image URLs
#define GITHUB_USER "DM2NT"
#define GITHUB_REPO "S50-Enclosure-Control"
#define GITHUB_BRANCH "main"
#define IMG_BASE_URL "https://raw.githubusercontent.com/" GITHUB_USER "/" GITHUB_REPO "/" GITHUB_BRANCH "/assets/status_images/"

// Regensensor Schwellwert (0 = trocken, 1 = Regen erkannt)
#define RAIN_THRESHOLD 0.5  // mm/h - Schließen bei Regen

// Servo-Geschwindigkeit (ms pro Grad)
const int servo_speed = 30;

// Sensor Update-Intervalle
const unsigned long RTC_UPDATE_INTERVAL = 60000;      // 60 Sekunden
const unsigned long GPS_SYNC_INTERVAL = 600000;       // 10 Minuten

// Pin-Definitionen
#define SERVO1_PIN 16  // Taster-Drücker (S50 Ein/Aus)
#define SERVO2_PIN 17  // Klappe
#define SERVO3_PIN 18  // Verriegelung

#define REED1_PIN 25   // Klappe geschlossen
#define REED2_PIN 26   // Verriegelung geschlossen
#define REED3_PIN 27   // Tubus in Standby

#define RAIN_RX_PIN 35      // RG-11 UART RX
#define RAIN_TX_PIN 4       // Unbenutzt, aber gültiger Output-Pin
#define HEATER_PIN 33       // Heizwiderstand 3Ω @ 5V = 8.3W (MOSFET IRLZ44N)

// ============= GLOBALE VARIABLEN =============

// Servo Objekte
Servo servo1, servo2, servo3;

// Servo Positionen
int servo1_pos = 90, servo2_pos = 90, servo3_pos = 90;

// Servo1 (Taster): 2 Positionen
int servo1_pos1 = 90, servo1_pos2 = 90;

// Servo2 (Klappe): 3 Positionen
int servo2_pos1 = 90, servo2_pos2 = 90, servo2_pos3 = 90;

// Servo3 (Verriegelung): 2 Positionen
int servo3_pos1 = 90, servo3_pos2 = 90;

// Reed-Status
bool reed1_state = false, reed2_state = false, reed3_state = false;
bool reed2_enabled = true;  // Riegelüberwachung aktiviert (kann deaktiviert werden)

// Regensensor RG-11 (ASCII "It's Raining" Mode)
bool rain_sensor_present = false;
bool rain_detected = false;  // true wenn Acc > 0
float rain_acc = 0.0;        // Regenmenge vom Sensor (Acc-Wert)
HardwareSerial rainSerial(1); // UART1 für RG-11
String last_rain_close = "";  // Timestamp der letzten Regen-Schließung

// Heizung
bool heater_on = false;
float dew_point = 0.0;
// Heizungs-Hysterese
float heater_hysteresis = 2.0;  // Aus Preferences geladen
// Heizungs-Modus: 0=Aktiviert (Auto), 1=Deaktiviert
int heater_mode = 0;  // Wird aus Preferences geladen

// RTC Status
bool rtc_present = false;  // Wird im Setup geprüft

// Scheduler/Planer
bool scheduler_enabled = false;
int schedule_open_hour = 20;    // 20:00 Uhr
int schedule_open_min = 0;
int schedule_close_hour = 3;    // 03:00 Uhr
int schedule_close_min = 0;
bool schedule_open_done = false;   // Verhindert mehrfaches Auslösen
bool schedule_close_done = false;

// Preferences
Preferences preferences;

// Wetter-Sensoren
HTU21D sht21_innen;
Adafruit_BMP085 bmp180_aussen;  // BMP180
Adafruit_BMP280 bmp280_aussen;  // BMP280
bool bmp180_present = false;    // Flag ob BMP180 vorhanden
bool bmp280_present = false;    // Flag ob BMP280 vorhanden
String bmp_sensor_type = "Keine";  // "BMP180" oder "BMP280"
float temp_innen = 0.0, hum_innen = 0.0;
float temp_aussen = 0.0, druck_aussen = 0.0;

// RTC mit millis() Tracking
RTC_DS3231 rtc;
DateTime lastRTCRead;
unsigned long lastRTCMillis = 0, lastRTCUpdate = 0;
String rtc_time_local = "--:--:--", rtc_time_utc = "--:--:--", rtc_date = "--.--.----";
int timezone_offset = 1;
bool is_dst = false;

// GPS
HardwareSerial gpsSerial(2);
TinyGPSPlus gps;
String gps_date = "--.--.----", gps_time = "--:--:--";
int gps_sats = 0;
bool gps_fix = false;
unsigned long last_gps_sync = 0;

// Gehäuse-Status
String status_text = "Initialisierung...";
String status_color = "#FFA500";
String last_error_message = "";  // Letzte Fehlermeldung für Interface

// Action Flags (für non-blocking Ausführung in loop)
enum PendingAction { NONE, OPEN, CLOSE, TOGGLE_S50 };
PendingAction pending_action = NONE;

// Webserver und DNS für AP-Modus
AsyncWebServer server(80);
// DNSServer dnsServer;  // Nicht mehr nötig - WiFiManager hat eigenen
bool apMode = false;

// WiFi Info
String current_ssid = "";
int wifi_rssi = 0;
String wifi_ip = "";

// Seestar S50 Ping
String seestar_ip = "192.168.1.100";  // Default IP
bool seestar_online = false;
bool seestar_online_last = false;  // Letzter Status für Statuswechsel-Erkennung
unsigned long last_ping_check = 0;

// ============= HELPER FUNCTIONS =============

// RTC Zeit mit millis() hochzählen für flüssige Anzeige
void updateRTCTime() {
  unsigned long currentMillis = millis();
  
  // RTC nur alle 60s neu auslesen (wenn vorhanden!)
  if (rtc_present && (currentMillis - lastRTCUpdate >= RTC_UPDATE_INTERVAL)) {
    lastRTCRead = rtc.now();
    lastRTCMillis = currentMillis;
    lastRTCUpdate = currentMillis;
  }
  
  // Berechne vergangene Sekunden seit letztem RTC-Read
  unsigned long elapsedSeconds = (currentMillis - lastRTCMillis) / 1000;
  DateTime currentTime = lastRTCRead + TimeSpan(elapsedSeconds);
  
  // Sommerzeit prüfen
  is_dst = isDST(currentTime.day(), currentTime.month(), currentTime.dayOfTheWeek());
  int local_offset = timezone_offset + (is_dst ? 1 : 0);
  
  // Lokalzeit berechnen
  DateTime localTime = currentTime + TimeSpan(0, local_offset, 0, 0);
  
  // Zeit formatieren
  char timeBufferLocal[9], timeBufferUTC[9], dateBuffer[11];
  sprintf(timeBufferLocal, "%02d:%02d:%02d", localTime.hour(), localTime.minute(), localTime.second());
  sprintf(timeBufferUTC, "%02d:%02d:%02d", currentTime.hour(), currentTime.minute(), currentTime.second());
  sprintf(dateBuffer, "%02d.%02d.%04d", localTime.day(), localTime.month(), localTime.year());
  
  rtc_time_local = String(timeBufferLocal);
  rtc_time_utc = String(timeBufferUTC);
  rtc_date = String(dateBuffer);
}

// Berechne ob Sommerzeit aktiv ist (Europa)
bool isDST(int day, int month, int dow) {
  if (month < 3 || month > 10) return false;
  if (month > 3 && month < 10) return true;
  
  int lastSunday = day - dow;
  while (lastSunday + 7 <= 31) lastSunday += 7;
  
  if (month == 3) return (day >= lastSunday);
  if (month == 10) return (day < lastSunday);
  
  return false;
}

// Synchronisiere RTC mit GPS-Zeit
void syncRTCwithGPS() {
  if (!rtc_present) return;  // Ohne RTC kein Sync möglich!
  if (!gps.date.isValid() || !gps.time.isValid()) return;
  
  DateTime gpsTime(gps.date.year(), gps.date.month(), gps.date.day(),
                   gps.time.hour(), gps.time.minute(), gps.time.second());
  
  rtc.adjust(gpsTime);
  lastRTCRead = gpsTime;
  lastRTCMillis = millis();
  lastRTCUpdate = millis();
  
  Serial.println("RTC mit GPS synchronisiert (UTC)");
  Serial.printf("GPS-Zeit: %02d.%02d.%04d %02d:%02d:%02d UTC\n",
                gps.date.day(), gps.date.month(), gps.date.year(),
                gps.time.hour(), gps.time.minute(), gps.time.second());
}

// BMP Sensor Wrapper-Funktionen (beide Sensoren unterstützen)
float readBMPTemperature() {
  if (bmp280_present) {
    return bmp280_aussen.readTemperature();
  } else if (bmp180_present) {
    return bmp180_aussen.readTemperature();
  }
  return 0.0;
}

float readBMPPressure() {
  if (bmp280_present) {
    return bmp280_aussen.readPressure() / 100.0;  // Pa → hPa
  } else if (bmp180_present) {
    return bmp180_aussen.readPressure() / 100.0;  // Pa → hPa
  }
  return 0.0;
}

bool isBMPPresent() {
  return (bmp180_present || bmp280_present);
}

// Langsame Servo-Bewegung
void moveServoSlow(Servo &servo, int &current_pos, int target_pos) {
  if (current_pos < target_pos) {
    for (int pos = current_pos; pos <= target_pos; pos++) {
      servo.write(pos);
      delay(servo_speed);
      yield();  // Gib anderen Tasks Zeit
    }
  } else {
    for (int pos = current_pos; pos >= target_pos; pos--) {
      servo.write(pos);
      delay(servo_speed);
      yield();  // Gib anderen Tasks Zeit
    }
  }
  current_pos = target_pos;
}

// RG-11 Daten lesen und parsen (ASCII Protokoll "It's Raining" Mode)
// Format: "Acc X.XX\r\n"
// Acc 1.00 = Regen, Acc 0.00 = trocken
void readRainSensor() {
  static char buffer[32];
  static int buf_pos = 0;
  static unsigned long last_debug = 0;
  
  while (rainSerial.available()) {
    char c = rainSerial.read();
    
    // Zeichen in Buffer sammeln
    if (buf_pos < 31) {
      buffer[buf_pos++] = c;
      buffer[buf_pos] = 0;  // Null-terminiert
    }
    
    // Bei \n → Frame komplett
    if (c == '\n') {
      // Suche nach "Acc"
      char* acc_pos = strstr(buffer, "Acc");
      if (acc_pos != NULL) {
        // Parse die Zahl nach "Acc "
        float value = 0.0;
        if (sscanf(acc_pos, "Acc %f", &value) == 1) {
          rain_sensor_present = true;
          
          // Vorheriger Wert speichern
          float old_acc = rain_acc;
          rain_acc = value;
          
          // Status aktualisieren
          rain_detected = (rain_acc > 0.0);
          
          // Debug bei Änderung
          if (rain_acc != old_acc) {
            if (rain_detected) {
              Serial.printf("💧 RG-11: REGEN! Acc=%.2f\n", rain_acc);
            } else {
              Serial.printf("☀️ RG-11: TROCKEN! Acc=%.2f\n", rain_acc);
            }
          }
        }
      }
      
      // Buffer zurücksetzen
      buf_pos = 0;
      buffer[0] = 0;
    }
    
    // Buffer overflow vermeiden
    if (buf_pos >= 31) {
      buf_pos = 0;
      buffer[0] = 0;
    }
  }
  
  // Debug alle 10s
  if (millis() - last_debug > 10000) {
    if (rain_sensor_present) {
      Serial.printf("RG-11: Acc=%.2f, Raining=%d\n", rain_acc, rain_detected);
    }
    last_debug = millis();
  }
}

// Reed-Kontakte auslesen
void readReedContacts() {
  reed1_state = !digitalRead(REED1_PIN);
  reed2_state = !digitalRead(REED2_PIN);
  reed3_state = !digitalRead(REED3_PIN);
}

// Taupunkt berechnen (Magnus-Formel)
float calculateDewPoint(float temp_c, float humidity) {
  // Sicherheitsabfragen
  if (humidity < 1.0) humidity = 1.0;
  if (humidity > 100.0) humidity = 100.0;
  if (temp_c < -40.0 || temp_c > 80.0) return 0.0;  // Ungültige Temperatur
  
  // Magnus-Formel Konstanten
  const float a = 17.27;
  const float b = 237.7;
  
  // Berechne alpha
  float alpha = ((a * temp_c) / (b + temp_c)) + log(humidity / 100.0);
  
  // Berechne Taupunkt
  float dewpoint = (b * alpha) / (a - alpha);
  
  // Sicherheitscheck Ergebnis
  if (isnan(dewpoint) || isinf(dewpoint)) return 0.0;
  if (dewpoint < -40.0 || dewpoint > 80.0) return 0.0;
  
  return dewpoint;
}

// Seestar S50 Ping Check
void checkSeestarOnline() {
  if (seestar_ip == "" || seestar_ip == "0.0.0.0") {
    seestar_online = false;
    return;
  }
  
  // Ping mit 2 Sekunden Timeout
  seestar_online = Ping.ping(seestar_ip.c_str(), 2);
  
  // Nur ausgeben wenn sich Status geändert hat!
  if (seestar_online != seestar_online_last) {
    if (seestar_online) {
      Serial.printf("✓ Seestar S50 online (%s)\n", seestar_ip.c_str());
    } else {
      Serial.printf("✗ Seestar S50 offline (%s)\n", seestar_ip.c_str());
    }
    seestar_online_last = seestar_online;  // Status merken
  }
}

// Zeitgesteuerter Planer (Scheduler)
void checkScheduler() {
  if (!scheduler_enabled) return;
  if (!rtc_present) return;  // Ohne RTC kein Scheduler möglich!
  
  // RTC-Zeit aktualisieren
  DateTime now = rtc.now();
  DateTime local = now + TimeSpan(0, timezone_offset + (is_dst ? 1 : 0), 0, 0);
  
  int current_hour = local.hour();
  int current_min = local.minute();
  
  // Prüfe ÖFFNEN
  if (current_hour == schedule_open_hour && current_min == schedule_open_min) {
    if (!schedule_open_done) {
      Serial.printf("⏰ SCHEDULER: Öffnungszeit erreicht (%02d:%02d)\n", 
                    schedule_open_hour, schedule_open_min);
      
      // WICHTIG: Prüfe Regen!
      if (rain_detected && rain_sensor_present) {
        Serial.println("⚠️ ÖFFNEN ABGEBROCHEN: Regen erkannt!");
        last_error_message = "⏰ Geplantes Öffnen abgebrochen - Regen!";
      } else {
        Serial.println("→ Starte Öffnen...");
        pending_action = OPEN;
      }
      
      schedule_open_done = true;
    }
  } else {
    schedule_open_done = false;  // Reset für nächsten Tag
  }
  
  // Prüfe SCHLIEßEN
  if (current_hour == schedule_close_hour && current_min == schedule_close_min) {
    if (!schedule_close_done) {
      Serial.printf("⏰ SCHEDULER: Schließzeit erreicht (%02d:%02d)\n", 
                    schedule_close_hour, schedule_close_min);
      Serial.println("→ Starte Schließen...");
      pending_action = CLOSE;
      schedule_close_done = true;
    }
  } else {
    schedule_close_done = false;  // Reset für nächsten Tag
  }
}

// Heizungs-Steuerung (mit Hysterese)
void controlHeater() {
  // Taupunkt IMMER berechnen (auch bei offenem Gehäuse für Anzeige!)
  dew_point = calculateDewPoint(temp_innen, hum_innen);
  
  // Wenn Heizung deaktiviert (heater_mode = 1) → nichts tun
  if (heater_mode == 1) {
    // Heizung ist deaktiviert
    if (heater_on) {
      digitalWrite(HEATER_PIN, LOW);
      heater_on = false;
      Serial.println("Heizung AUS (Deaktiviert)");
    }
    return;
  }
  
  // Ab hier: Auto-Modus (heater_mode == 0)
  
  // Nur wenn Gehäuse geschlossen (Reed1 + Reed2, aber Reed2 optional)
  readReedContacts();
  
  // Prüfe Reed1 immer, Reed2 nur wenn aktiviert
  if (!reed1_state || (reed2_enabled && !reed2_state)) {
    // Gehäuse offen oder nicht verriegelt → Heizung AUS
    if (heater_on) {
      digitalWrite(HEATER_PIN, LOW);
      heater_on = false;
      Serial.println("Heizung AUS (Sternwarte offen)");
    }
    return;
  }
  
  // Heizungs-Logik mit Hysterese (INNEN-Temperatur!)
  if (!heater_on) {
    // Heizung ist AUS → AN wenn Innentemp <= Taupunkt
    if (temp_innen <= dew_point) {
      digitalWrite(HEATER_PIN, HIGH);
      heater_on = true;
      Serial.printf("Heizung AN (Innen: %.1f°C <= Taupunkt: %.1f°C)\n", temp_innen, dew_point);
    }
  } else {
    // Heizung ist AN → AUS wenn Innentemp > Taupunkt + Hysterese
    if (temp_innen > dew_point + heater_hysteresis) {
      digitalWrite(HEATER_PIN, LOW);
      heater_on = false;
      Serial.printf("Heizung AUS (Innen: %.1f°C > Taupunkt+Hyst: %.1f°C)\n", temp_innen, dew_point + heater_hysteresis);
    }
  }
}

// Berechne Gehäuse-Status für Text-Anzeige
void updateStatusText() {
  readReedContacts();
  
  // Effektiver Reed2-Status (immer true wenn deaktiviert)
  bool reed2_effective = reed2_enabled ? reed2_state : true;
  
  // GESCHLOSSEN GRÜN: Alles zu und verriegelt
  if (reed1_state && reed2_effective && reed3_state) {
    status_text = "GESCHLOSSEN ✓";
    status_color = "#00FF00";
    return;
  }
  
  // GEÖFFNET GRÜN: Klappe auf Position 2 UND Reed1+2 inaktiv
  if (servo2_pos == servo2_pos2 && !reed1_state && (reed2_enabled ? !reed2_state : true)) {
    status_text = "GEÖFFNET ✓";
    status_color = "#00FF00";
    return;
  }
  
  // HALBOFFEN: Position 3
  if (servo2_pos == servo2_pos3) {
    status_text = "HALBOFFEN";
    status_color = "#FFA500";
    return;
  }
  
  // FEHLER ROT: Klappe soll zu sein, aber Reeds nicht aktiv (nur Reed1 prüfen wenn Reed2 deaktiviert)
  if (servo2_pos == servo2_pos1 && (!reed1_state || (reed2_enabled && !reed2_state))) {
    status_text = "FEHLER!";
    status_color = "#FF0000";
    return;
  }
  
  // IN BEWEGUNG
  status_text = "IN BEWEGUNG";
  status_color = "#FFA500";
}

String getStatusDetail() {
  String detail = "";
  
  // Spezifische Fehlermeldungen bei geschlossener Klappe
  if (servo2_pos == servo2_pos1) {  // Klappe soll geschlossen sein
    // Reed2-Check nur wenn aktiviert
    bool reed2_check = reed2_enabled ? !reed2_state : false;
    
    if (!reed1_state && reed2_check) {
      return "⚠️ Klappe UND Verriegelung klemmen!";
    } else if (!reed1_state) {
      return "⚠️ Klappe klemmt - nicht geschlossen!";
    } else if (reed2_check) {
      return "⚠️ Verriegelung klemmt - nicht verriegelt!";
    }
  }
  
  // Normale Status-Anzeige
  if (reed1_state) detail += "Klappe OK ";
  else detail += "Klappe offen ";
  
  // Reed2 nur anzeigen wenn aktiviert
  if (reed2_enabled) {
    if (reed2_state) detail += "| Riegel OK ";
    else detail += "| Riegel offen ";
  }
  
  if (reed3_state) detail += "| Tubus OK";
  else detail += "| Tubus aktiv";
  
  return detail;
}

// ============= ABLAUF-FUNKTIONEN =============
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
void loop() {
  // Führe geplante Aktionen aus (non-blocking, kein Watchdog-Problem)
  if (pending_action != NONE) {
    PendingAction action = pending_action;
    pending_action = NONE;  // Reset sofort (verhindert doppelte Ausführung)
    
    switch (action) {
      case OPEN:
        {
          bool success = openDome();
          if (success) {
            Serial.println("✓ Öffnen erfolgreich");
          } else {
            Serial.println("✗ Öffnen fehlgeschlagen");
          }
        }
        break;
        
      case CLOSE:
        {
          bool success = closeDome();
          if (success) {
            Serial.println("✓ Schließen erfolgreich");
          } else {
            Serial.println("⚠ Nur halboffen (Tubus nicht eingefahren)");
          }
        }
        break;
        
      case TOGGLE_S50:
        toggleS50();
        Serial.println("✓ S50 Toggle ausgeführt");
        break;
        
      default:
        break;
    }
  }
  
  // Tubus-Überwachung: Automatisches Halböffnen wenn Tubus ausfährt
  // ABER NUR wenn Gehäuse GESCHLOSSEN ist!
  static bool last_tubus_standby = true;  // Startzustand
  readReedContacts();
  
  // Erkenne Übergang: Standby → Aktiv (Tubus fährt aus)
  if (last_tubus_standby && !reed3_state) {
    // Nur auf halboffen fahren wenn Klappe GESCHLOSSEN ist (nicht bei offen!)
    if (servo2_pos == servo2_pos1) {
      Serial.println("⚠️ TUBUS FÄHRT AUS! Öffne Klappe automatisch auf HALBOFFEN...");
      moveServoSlow(servo2, servo2_pos, servo2_pos3);
      servo2_pos = servo2_pos3;
      preferences.begin("s50-enclosure", false);
      preferences.putInt("servo2", servo2_pos);
      preferences.end();
      Serial.println("✓ Klappe auf HALBOFFEN (Sicherheit)");
    } else {
      Serial.println("⚠️ TUBUS FÄHRT AUS, aber Klappe ist bereits offen → keine Änderung");
    }
  }
  
  last_tubus_standby = reed3_state;
  
  // GPS Daten einlesen
  while (gpsSerial.available() > 0) {
    gps.encode(gpsSerial.read());
  }
  
  // GPS -> RTC Sync (alle 10 Minuten wenn Fix vorhanden)
  if (gps.location.isValid() && gps.date.isValid() && gps.time.isValid()) {
    if (millis() - last_gps_sync > GPS_SYNC_INTERVAL || last_gps_sync == 0) {
      syncRTCwithGPS();
      last_gps_sync = millis();
    }
  }
  
  // Heizungs-Steuerung (alle 10 Sekunden prüfen)
  static unsigned long last_heater_check = 0;
  if (millis() - last_heater_check > 10000 || last_heater_check == 0) {
    controlHeater();
    last_heater_check = millis();
  }
  
  // Zeitplaner prüfen (jede Minute)
  static unsigned long last_scheduler_check = 0;
  if (millis() - last_scheduler_check > 60000 || last_scheduler_check == 0) {
    checkScheduler();
    last_scheduler_check = millis();
  }
  
  // WiFi Signal-Stärke aktualisieren (alle 5 Sekunden)
  static unsigned long last_wifi_update = 0;
  if (!apMode && (millis() - last_wifi_update > 5000 || last_wifi_update == 0)) {
    wifi_rssi = WiFi.RSSI();
    last_wifi_update = millis();
  }
  
  // Seestar S50 Ping Check (alle 5 Sekunden)
  if (!apMode && (millis() - last_ping_check > 5000 || last_ping_check == 0)) {
    checkSeestarOnline();
    last_ping_check = millis();
  }
  
  // Regensensor kontinuierlich auslesen (nicht-blockierend)
  if (rain_sensor_present) {
    readRainSensor();  // Verarbeitet alle verfügbaren Frames
    
    static unsigned long last_rain_check = 0;
    static bool rain_emergency_triggered = false;
    
    // Prüfe Regensensor alle 10s
    if (millis() - last_rain_check >= 10000) {
      last_rain_check = millis();
      
      // Wenn Sensor Regen meldet (Acc > 0) → sofort schließen
      if (rain_detected && !rain_emergency_triggered) {
        Serial.printf("⚠️ REGEN ERKANNT! (Acc=%.2f) Starte Notschließung...\n", rain_acc);
        emergencyRainClose();
        rain_emergency_triggered = true;
        // last_rain_close wird in emergencyRainClose() gesetzt
        // last_error_message wird nur bei Fehler gesetzt
      }
      
      // Wenn wieder trocken → Reset
      if (!rain_detected && rain_emergency_triggered) {
        rain_emergency_triggered = false;
        Serial.println("✓ Sensor meldet wieder TROCKEN");
      }
    }
  }
  
  delay(10);
}

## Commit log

2026-02-27 Repo-Struktur erstellt
    [S50 Boden Rev 0.8.stl, S50 Housing Rev0.8.stl, S50 Klappe Rev 0_8.stl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]
2026-02-27 firmware and pcb data added
    [S50_Controller_Rev0_4.brd]
2026-02-27 New STL uploaded
    [S50 Klappe Rev 0.8.stl, S50 Schleifringschutz_Rev0.8.stl, S50 Verriegelung Rev 0.8.stl]
2026-05-31 Update README with component changes and notes
    Removed references to the Davis Anemometer and updated the servo model from MG996R to MS24. Added notes on non-functionality for certain features and updated acknowledgments.
